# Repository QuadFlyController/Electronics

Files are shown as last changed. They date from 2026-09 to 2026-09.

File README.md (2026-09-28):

# QuadFlyController - Flight Controller Hardware

A high-performance, compact, 4-layer flight controller PCB engineered for quadcopters and small UAVs. Built around the STMicroelectronics STM32F411CEU6 MCU, featuring high-rate low-noise motion sensing, barometric altitude tracking, robust power management with dual-source automatic switching, and standard 30.5 mm × 30.5 mm mounting.

---

## 🚀 Key Specifications

| Subsystem | Component | Description |
| :--- | :--- | :--- |
| **Microcontroller (MCU)** | **STM32F411CEU6** | ARM Cortex-M4 @ 100 MHz, FPU, 512 KB Flash, 128 KB SRAM, external 25 MHz HSE oscillator |
| **Inertial Measurement (IMU)** | **ICM-42688-P** | High-precision 6-axis gyroscope & accelerometer on dedicated high-speed SPI bus with interrupt line |
| **Barometer / Altimeter** | **BMP390** | Ultra-low noise barometric pressure sensor on SPI bus for altitude hold |
| **Switching Regulator (Buck)** | **TPS62933** | High-efficiency 3A synchronous step-down converter providing stable +5V rail from battery |
| **Linear Regulator (LDO)** | **AP2112K-3.3** | Ultra-low dropout, low-noise 600 mA 3.3V LDO for clean MCU and analog sensor rails |
| **Power Path Switching** | **TPS2115A** | Seamless automatic power multiplexer between USB VBUS (+5V) and internal Buck converter (+5V) |
| **Transient Protection** | **SMBJ18A** | Bidirectional TVS diode protection on battery input |
| **USB Protection** | **USBLC6-2SC6** | Ultra-low capacitance ESD protection array on USB D+/D- lines |
| **USB Interface** | **USB Type-C (16-pin)** | Firmware flashing (DFU), telemetry, and configuration interface |
| **ESC Interface** | **JST-SH 8-Pin (1.0 mm)** | Standard 4-in-1 ESC connector (VBAT, GND, Motors 1–4, Current sensing) |

---

## 📐 PCB & Mechanical Specifications

- **Dimensions:** 45.0 mm × 45.0 mm with 3.5 mm corner radius
- **Mounting Hole Pattern:** Standard **30.5 mm × 30.5 mm**, 4.3 mm holes (M4, compatible with anti-vibration silicone grommets down to M3 hardware)
- **Layer Stack:** **4-Layer PCB**
  - **F.Cu (Top Layer):** High-speed signals, component breakout, top ground pour
  - **In1.Cu (Inner Layer 1):** Solid ground reference plane (GND)
  - **In2.Cu (Inner Layer 2):** Power distribution (+5V, +3.3V, +BATT) and cross-layer routing
  - **B.Cu (Bottom Layer):** Bottom ground plane and secondary signal routing
- **3D Mechanical Model:** Full 3D STEP model available in [`FlightController/CAD/FlightController.step`](FlightController/CAD/FlightController.step) for frame integration and enclosure design.

---

## 🔌 Pinout & Connector Definitions

### J3: 8-Pin JST-SH 4-in-1 ESC Connector (`SM08B-SRSS-TB`)

| Pin | Net Name | Function / Description |
| :---: | :--- | :--- |
| **1** | `+BATT` | Raw battery voltage input from ESC / PDB |
| **2** | `GND` | Power and signal ground return |
| **3** | `CUR` | Analog current sensing signal from ESC shunt sensor |
| **4** | `M1` | Motor 1 PWM / DShot signal output (STM32 Timer channel) |
| **5** | `M2` | Motor 2 PWM / DShot signal output (STM32 Timer channel) |
| **6** | `M3` | Motor 3 PWM / DShot signal output (STM32 Timer channel) |
| **7** | `M4` | Motor 4 PWM / DShot signal output (STM32 Timer channel) |
| **8** | `GND` | Ground return |

### External Pads & Test Points

- **UART (TX / RX):** External receiver connection (ELRS, Crossfire, SBUS) or GPS telemetry module.
- **SWD (SWDIO / SWCLK):** Hardware debug and in-circuit flashing with ST-Link or J-Link.
- **BOOT0:** Jumper/pad for STM32 internal ROM system bootloader (DFU mode over USB).
- **Status LEDs:**
  - `D1`: Power indicator
  - `D2`: User / Status LED (connected to STM32 GPIO)

---

## 📂 Repository Structure

```text
Electronics/
├── .gitignore                                 # Git ignore configuration
├── LICENSE                                    # License file
├── README.md                                  # Hardware documentation
├── FlightController_Schematic.pdf             # Exported full schematic PDF
│
└── FlightController/                          # KiCad 10 Project Directory
    ├── FlightController.kicad_pro             # KiCad project file
    ├── FlightController.kicad_pcb             # KiCad 4-layer PCB layout
    ├── FlightController.kicad_sch             # Root schematic sheet
    ├── MCU.kicad_sch                          # STM32F411CEU6 microcontroller sheet
    ├── IMU.kicad_sch                          # ICM-42688-P & BMP390 sensor sheet
    ├── PowerManagement.kicad_sch              # Power rails, buck, LDO, & USB sheet
    ├── fp-lib-table                           # Footprint library table
    ├── sym-lib-table                          # Symbol library table
    ├── fabrication-toolkit-options.json       # Production generation settings
    │
    ├── CAD/                                   # 3D Mechanical Models
    │   └── FlightController.step              # Complete 3D STEP assembly of the PCB
    │
    └── production/                            # Manufacturing & Assembly Files
        ├── FlightController.zip               # Gerbers & Drill archive (RS-274X / Excellon)
        ├── bom.csv                            # Bill of Materials (with LCSC part numbers)
        ├── positions.csv                      # Pick-and-Place (CPL) centroid coordinates
        ├── designators.csv                    # Component designator mapping
        └── netlist.ipc                        # IPC-D-356 netlist for bare-board testing
```

---

## 🏭 Manufacturing & Assembly (PCBA)

The files in [`FlightController/production/`](FlightController/production/) are pre-configured and formatted for rapid quoting and ordering with PCB manufacturers (such as JLCPCB, PCBWay, etc.):

1. **PCB Fabrication (Gerber & Drill):**
   - Upload [`FlightController/production/FlightController.zip`](FlightController/production/FlightController.zip).
   - Layers: **4 Layers**
   - Dimensions: **45 mm × 45 mm**
2. **SMT Assembly (PCBA):**
   - **BOM File:** Upload [`FlightController/production/bom.csv`](FlightController/production/bom.csv) (includes pre-matched LCSC part numbers for automated component sourcing).
   - **CPL / Centroid File:** Upload [`FlightController/production/positions.csv`](FlightController/production/positions.csv).
3. **Bare-Board Electrical Test:**
   - [`FlightController/production/netlist.ipc`](FlightController/production/netlist.ipc) is provided for automated flying-probe netlist verification.

---

## 🛠️ Design & Development Environment

- **EDA Software:** [KiCad EDA v10.x](https://www.kicad.org/)
- **To Open the Project:** Launch KiCad and open [`FlightController/FlightController.kicad_pro`](FlightController/FlightController.kicad_pro).
- **Viewing the Schematic without KiCad:** Open [`FlightController_Schematic.pdf`](FlightController_Schematic.pdf).

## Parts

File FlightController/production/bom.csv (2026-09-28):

Designator | Footprint | Quantity | Value | LCSC Part #
C1, C2, C28 | 0805 | 3 | 10μF X7R | C326595
C10, C11 | 0402 | 2 | 14pF C0G | C5360816
C12, C13, C14, C17, C18, C21, C27, C29, C30, C4, C7, C8, C9 | 0603 | 13 | 0.1μF X7R | C1590
C15 | 0603 | 1 | 2.2μF X7R | C43922
C16 | 0603 | 1 | 10nF X7R | C1589
C19, C20 | 1206 | 2 | 10μF X7R 50V | C89632
C22 | 0603 | 1 | 33nF X7R | C1614
C23 | 0603 | 1 | 0.1μF X7R 16V | C1590
C24, C25 | 1206 | 2 | 22μF X5R 35V | C342620
C26 | 0603 | 1 | 0.1μF X7R 35V | C385964
C3 | 0603 | 1 | 1μF X7R | C5199872
C5, C6 | 0603 | 2 | 4.7μF X7R | C6119822
CR1 | SMBJ18A | 1 | SMBJ18A | C10212
D1, D2 | 0603 | 2 | LED | C2286
J3 | XY-SM08B-SRSS-TB | 1 | SM08B-SRSS-TBLFSN | C54582896
L1 | 74439346068 | 1 | 74439346068 | C2041388
R1 | R_0603 | 1 | 100kΩ | C25803
R10 | 0603 | 1 | 53.6k | C23074
R11 | R_0603 | 1 | 10Ω | C22859
R12 | 0603 | 1 | 400 | C5841024
R13, R16, R5, R6, R7, R8 | R_0603 | 6 | 10kΩ | C25804
R14 | 1206 | 1 | 510k | C2774961
R15 | 1206 | 1 | 200k | C5720887
R17, R19 | R_0603 | 2 | 1kΩ | C21190
R18 | R_0603 | 1 | 1.5kΩ | C22843
R2, R3, R4 | R_0603 | 3 | 5.1kΩ | C23186
R9 | 0603 | 1 | 10.2k | C22772
U1 | SOT-23-5_HandSoldering | 1 | AP2112K-3.3 | C23380830
U2 | SOT-23-6_Handsoldering | 1 | USBLC6-2SC6 | C7519
U6 | SOT-583-8 | 1 | TPS62933 | C3200405
U7 | TPS2115ADRBR | 1 | TPS2115ADRBR | C140321
USB1 | USB-C_SMD-TYPE-C-31-M-12 | 1 | USB-TYPE-C-018 | C2927038
Y1 | CRYSTAL-SMD_4P-L3.2-W2.5-BL | 1 | 25MHz_GND24 | C9006

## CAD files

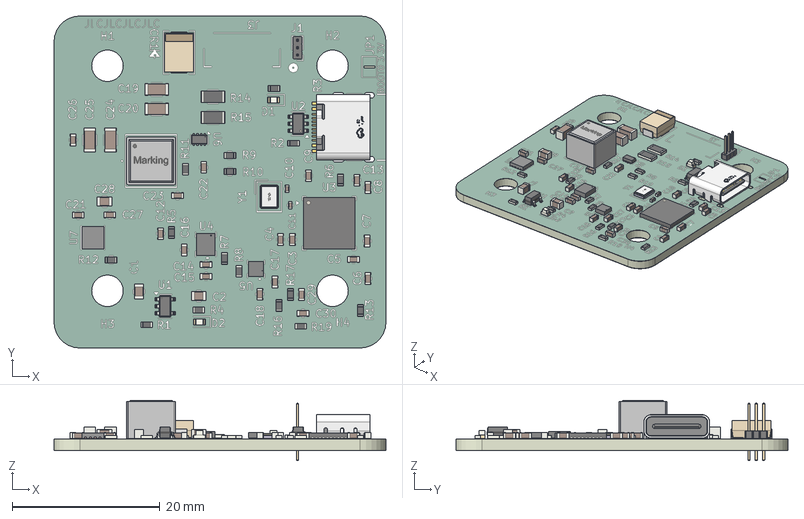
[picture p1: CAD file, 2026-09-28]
FlightController/CAD/FlightController.step
45.0 x 45.0 x 8.20 mm
C_0603_1608Metric x 21
R_0603_1608Metric x 17
C_0402_1005Metric x 2
C_0805_2012Metric x 3
PinHeader_1x03_P100mm_Vertical
C_1206_3216Metric x 4
QFN-48-1EP_7x7mm_Pitch0.5mm
LED_0603_1608Metric x 2
SOT-583-8
SOT-23-6
R_1206_3216Metric x 2
SOT-23-5
OSC-SMD_L3.2-W1.5-H0.8
BODY-SON
USB-C_SMD-TYPE-C-31-M-12
Fli650C_silkscreen x 2
Fli650C_soldermask x 2
Fli650C_PCB

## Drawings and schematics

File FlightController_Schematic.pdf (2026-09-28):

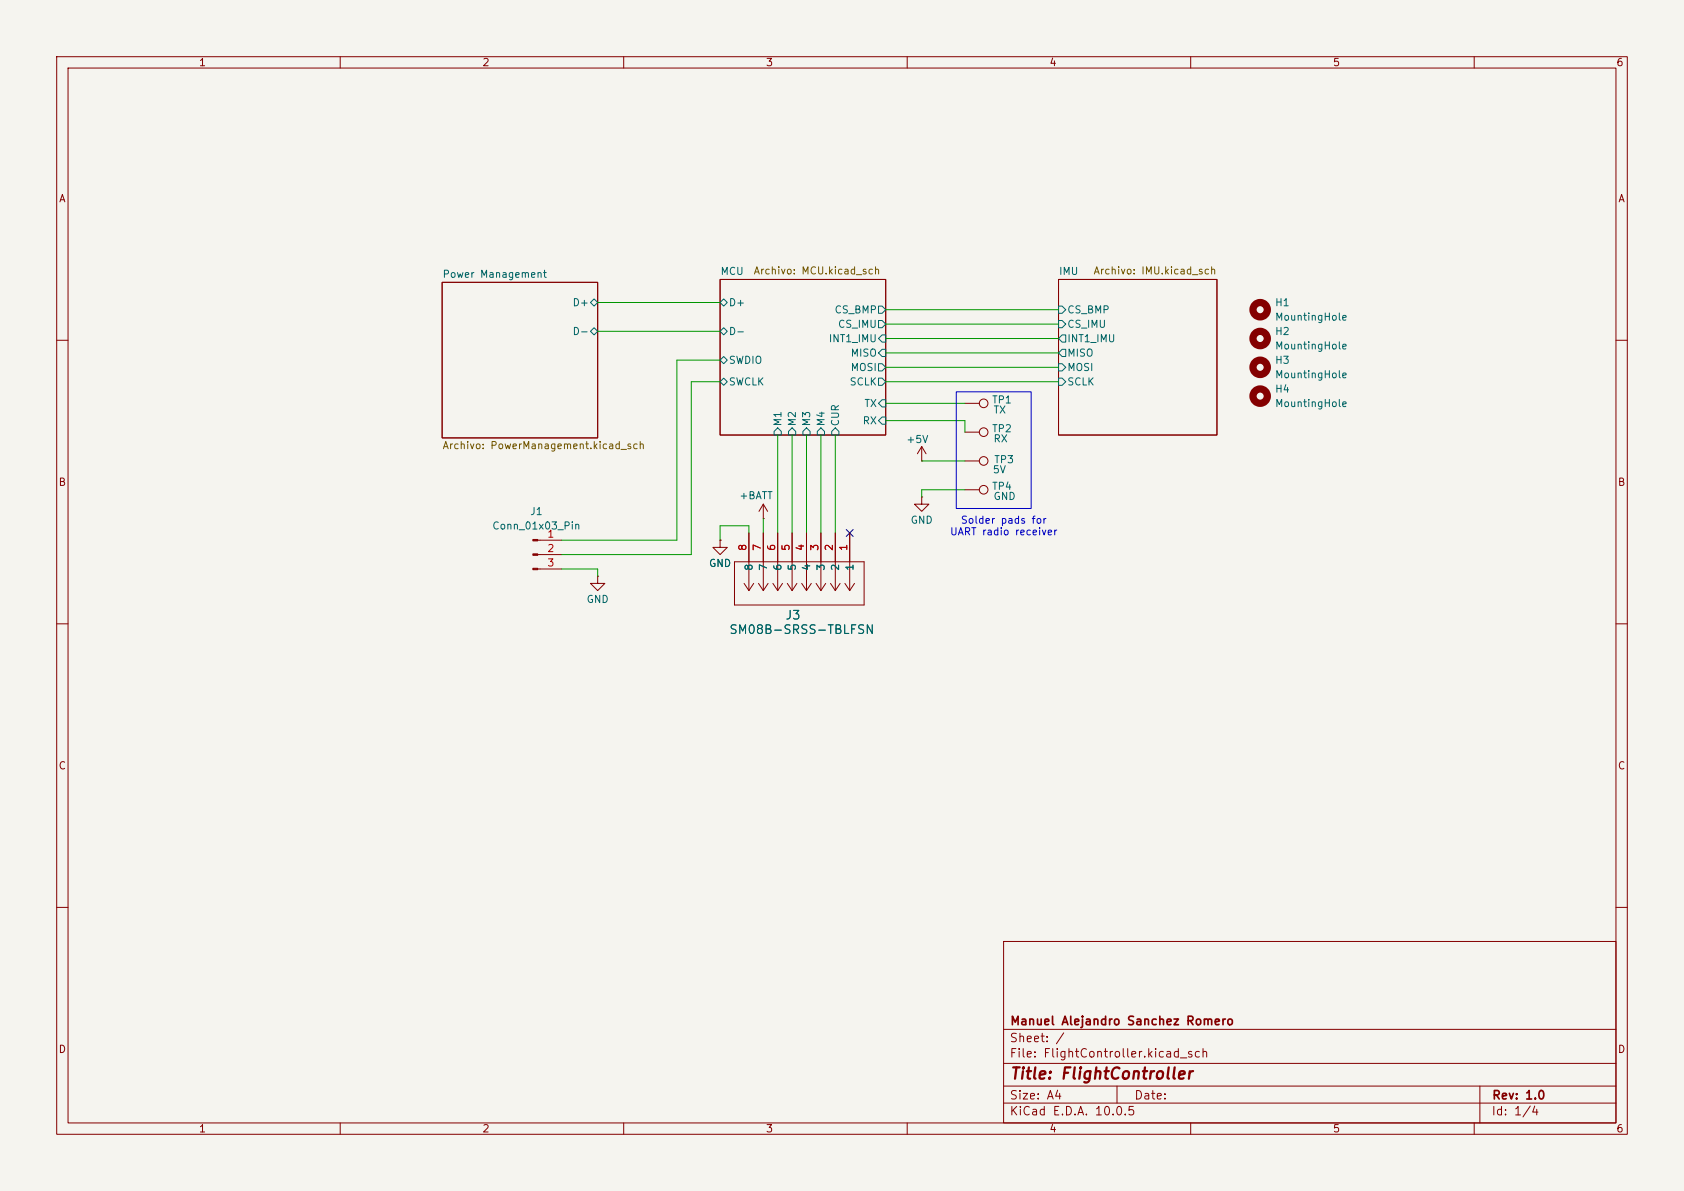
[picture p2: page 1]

SWDIO MCU Archivo: MCU.kicad_sch

Manuel Alejandro Sanchez Romero
Sheet: /
File: FlightController.kicad_sch
Title: FlightController

Size: A4 | Rev: 1.0
KiCad E.D.A. 10.0.5 | Id: 1/4

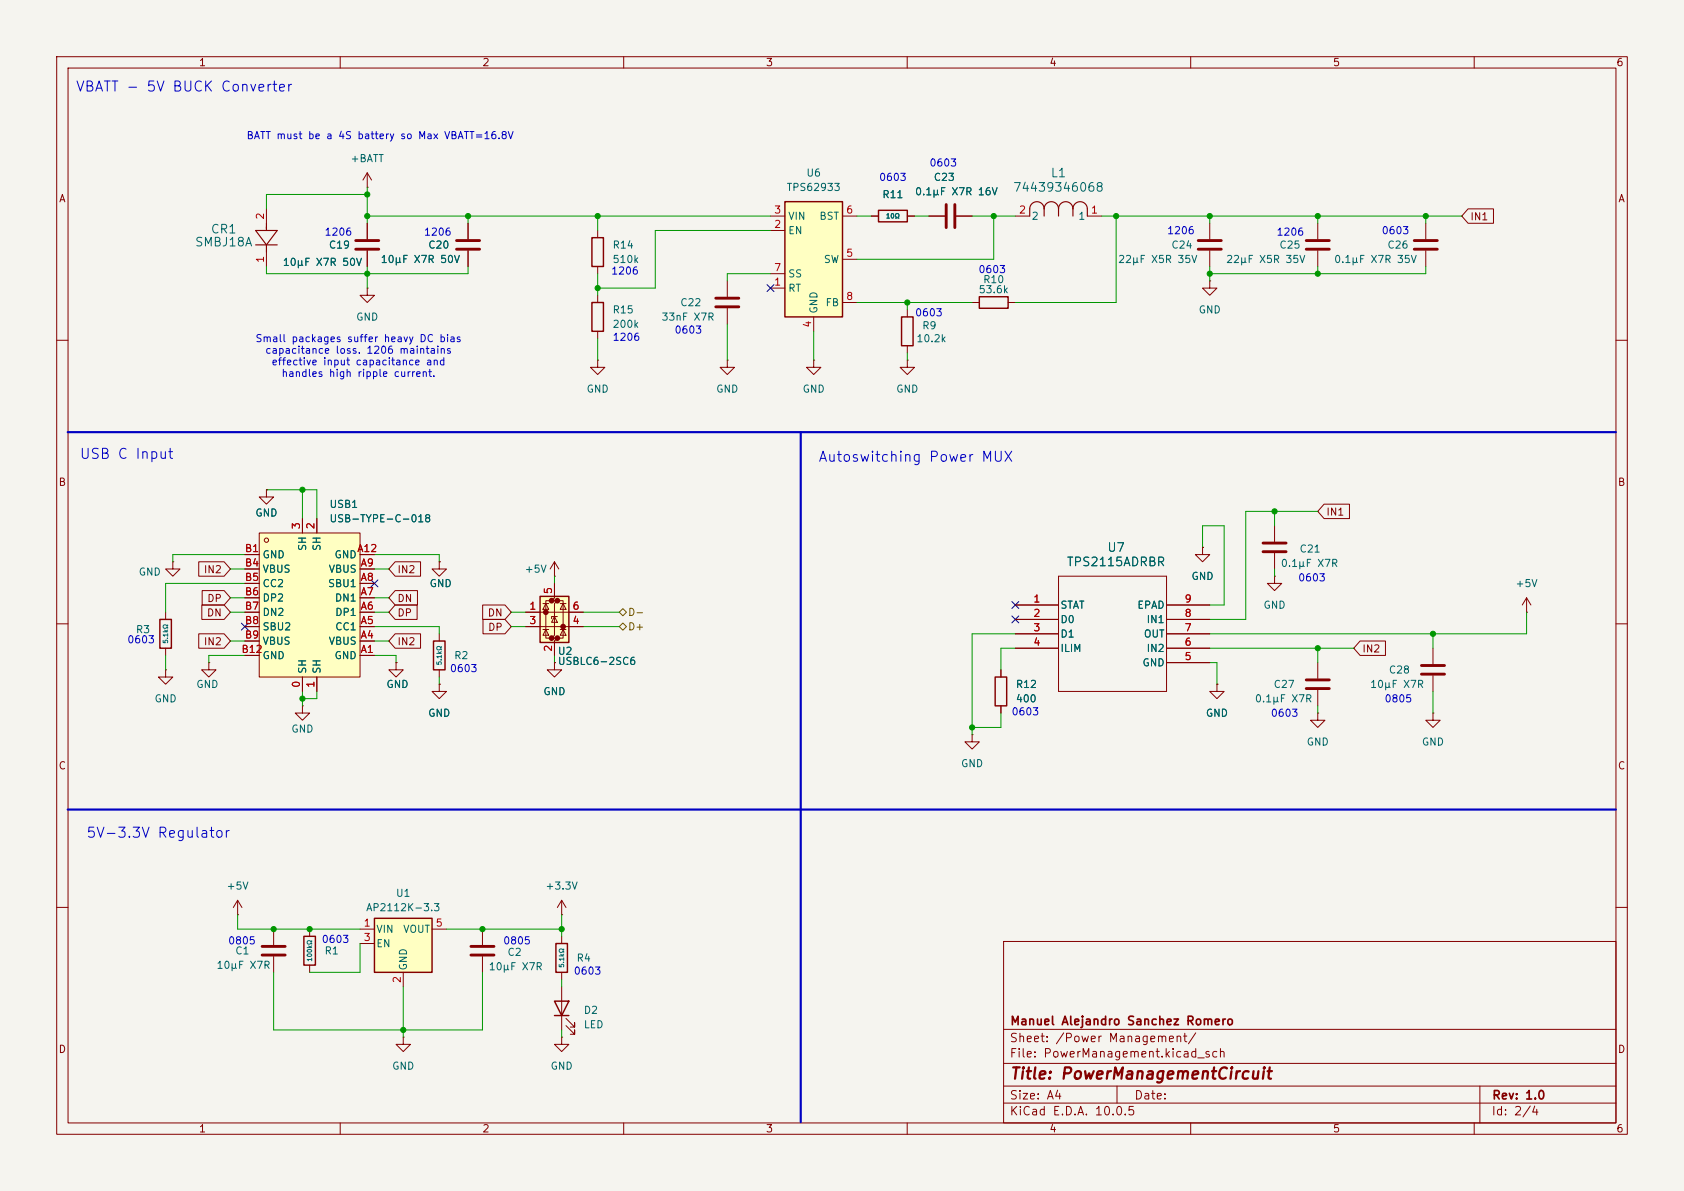
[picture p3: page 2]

200k GND
Small packages suffer heavy DC bias capacitance loss. 1206 maintains effective input capacitance and

3 GND A1 VBUS A4 CC1 A5 DP1 A6 DN1 A7 SBU1 A8 VBUS A9 GNDA12 GND B1

Manuel Alejandro Sanchez Romero
Sheet: /Power Management/
File: PowerManagement.kicad_sch
Title: PowerManagementCircuit

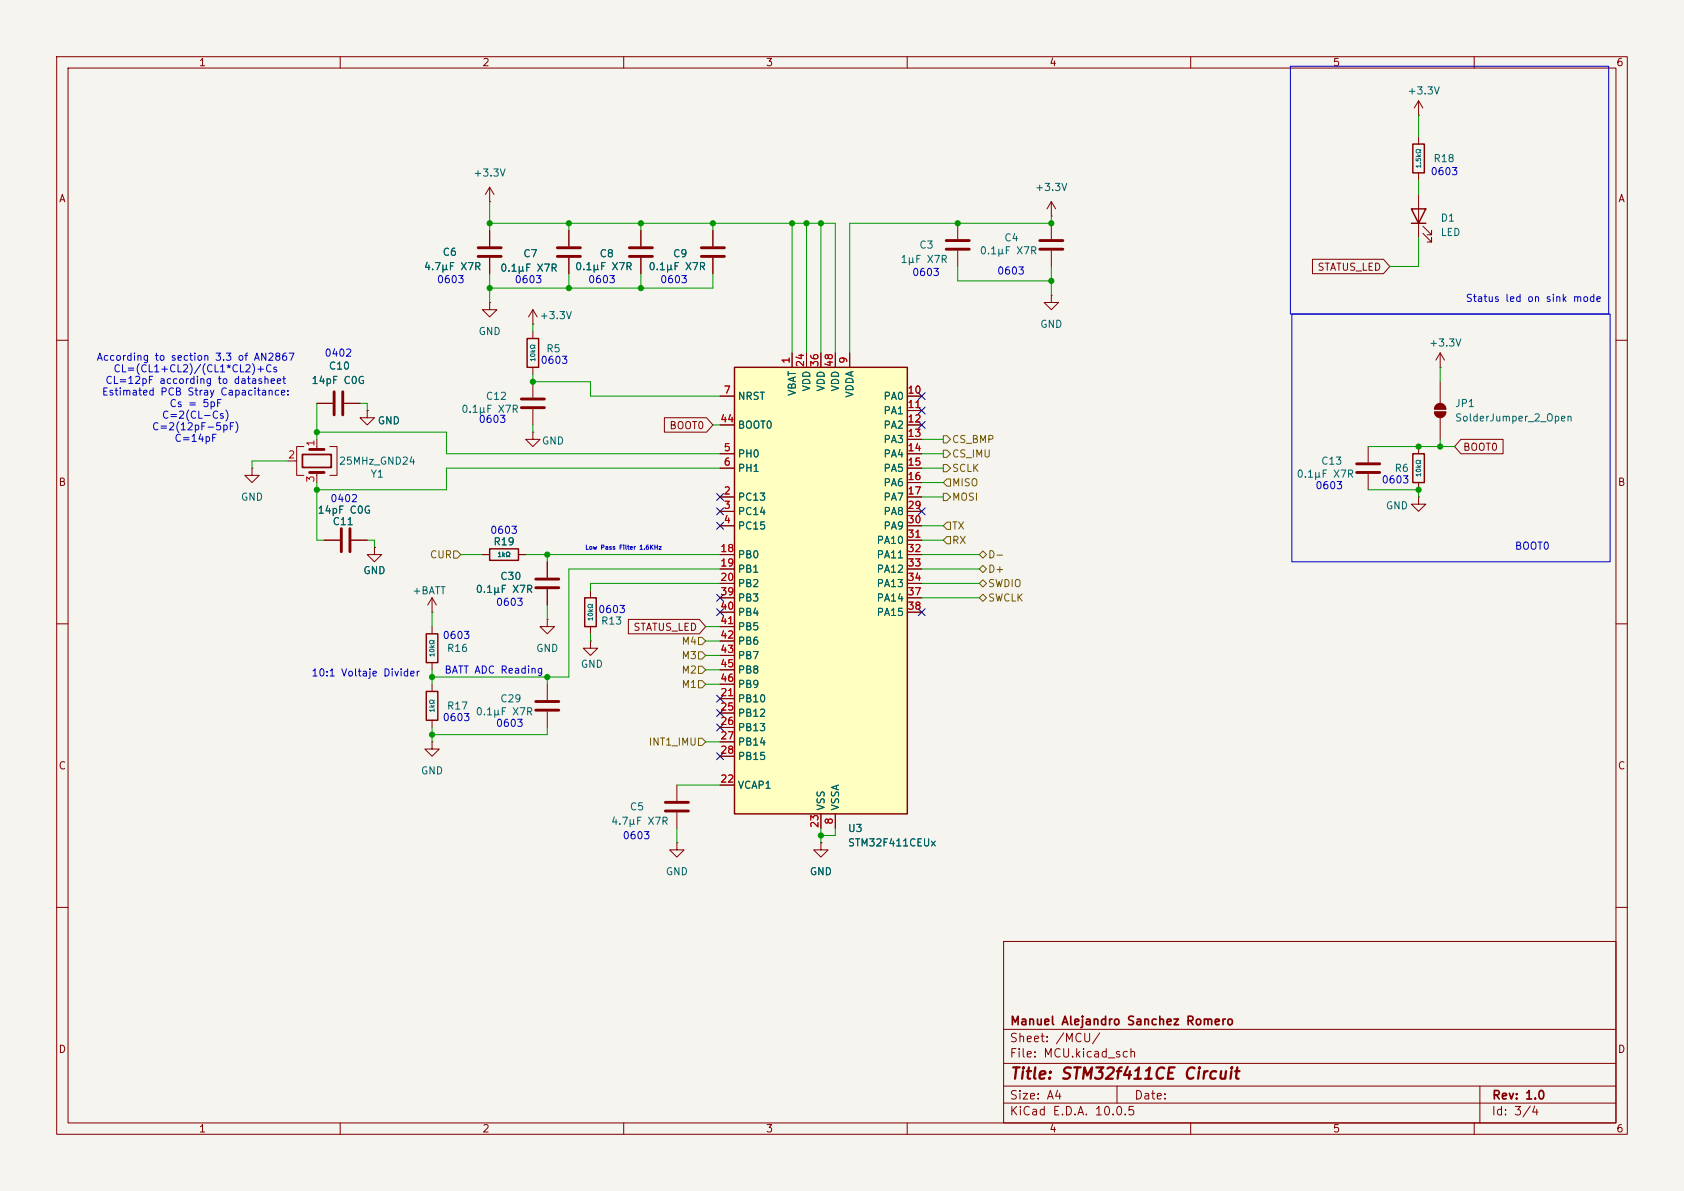
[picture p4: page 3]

According to section 3.3 of AN2867 CL=(CL1+CL2)/(CL1*CL2)+Cs

CL=12pF according to datasheet Estimated PCB Stray Capacitance: Cs = 5pF

Manuel Alejandro Sanchez Romero
Sheet: /MCU/
File: MCU.kicad_sch
Title: STM32f411CE Circuit

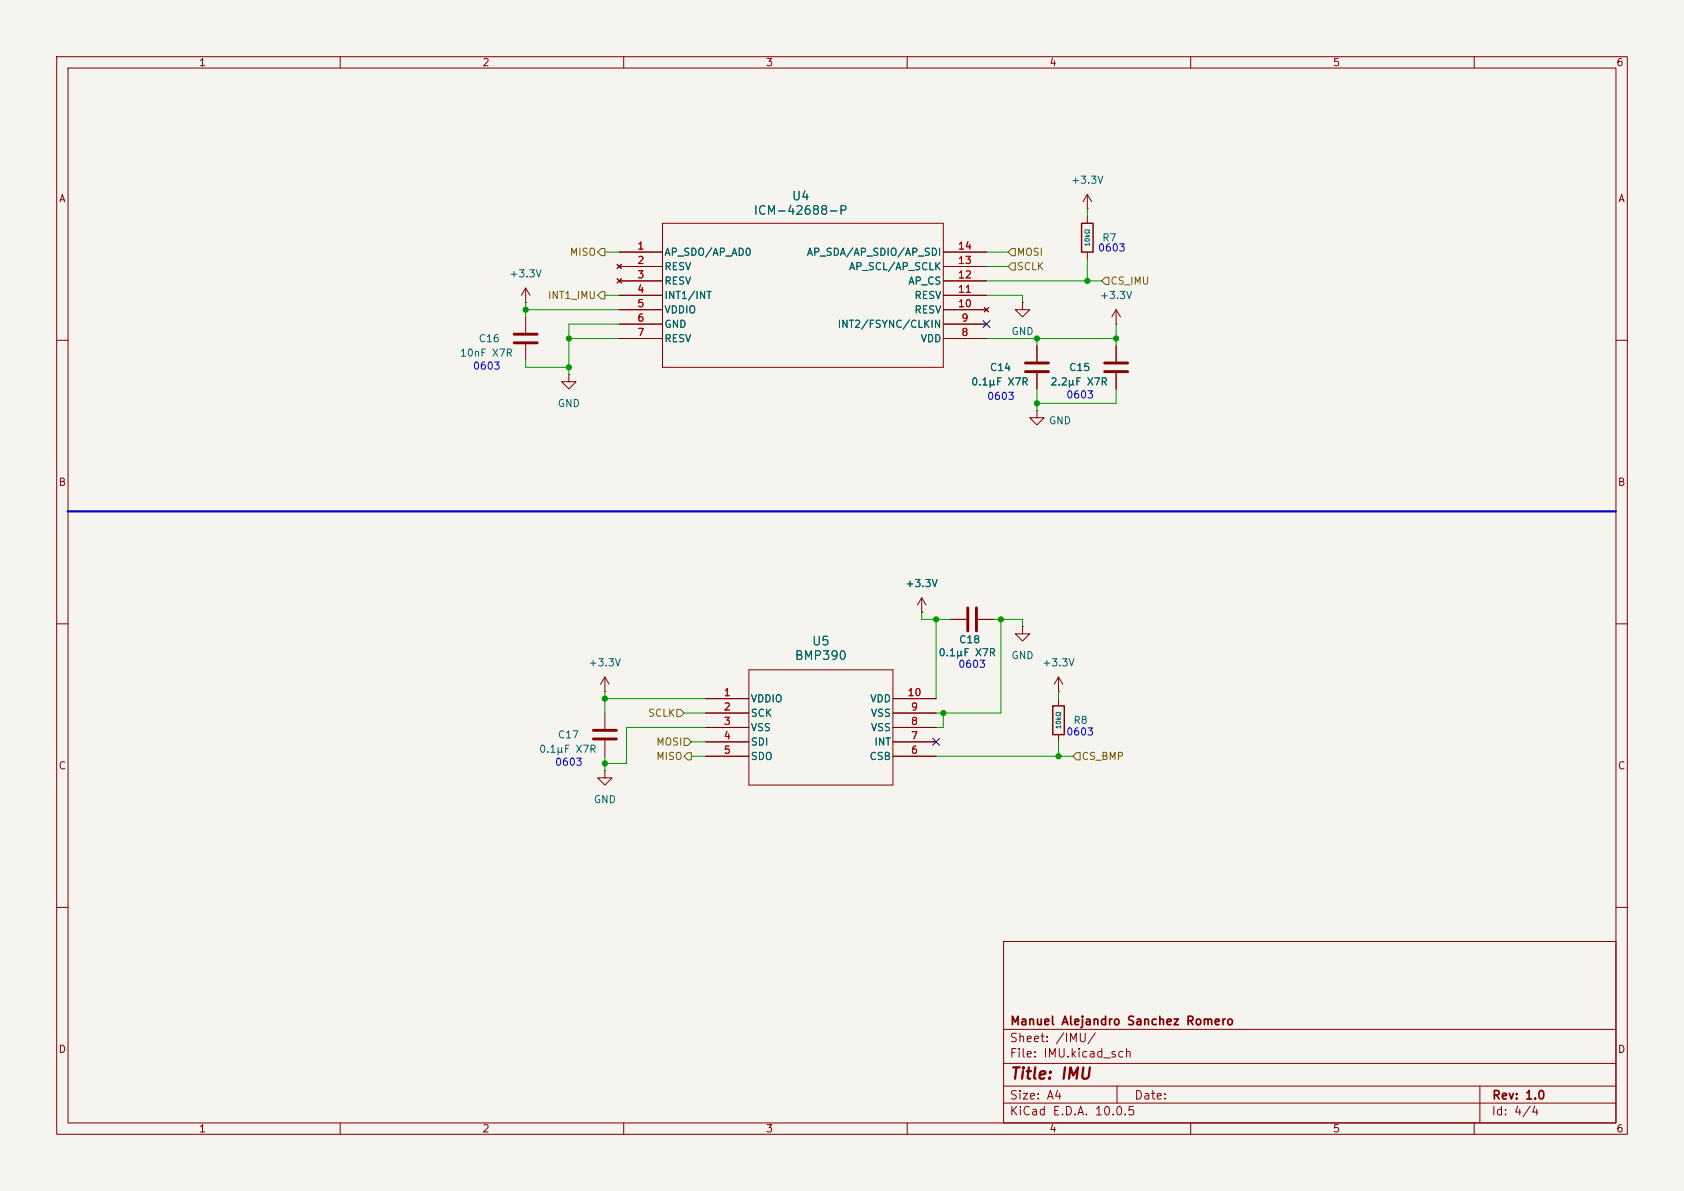
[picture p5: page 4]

Manuel Alejandro Sanchez Romero
Sheet: /IMU/
File: IMU.kicad_sch
Title: IMU

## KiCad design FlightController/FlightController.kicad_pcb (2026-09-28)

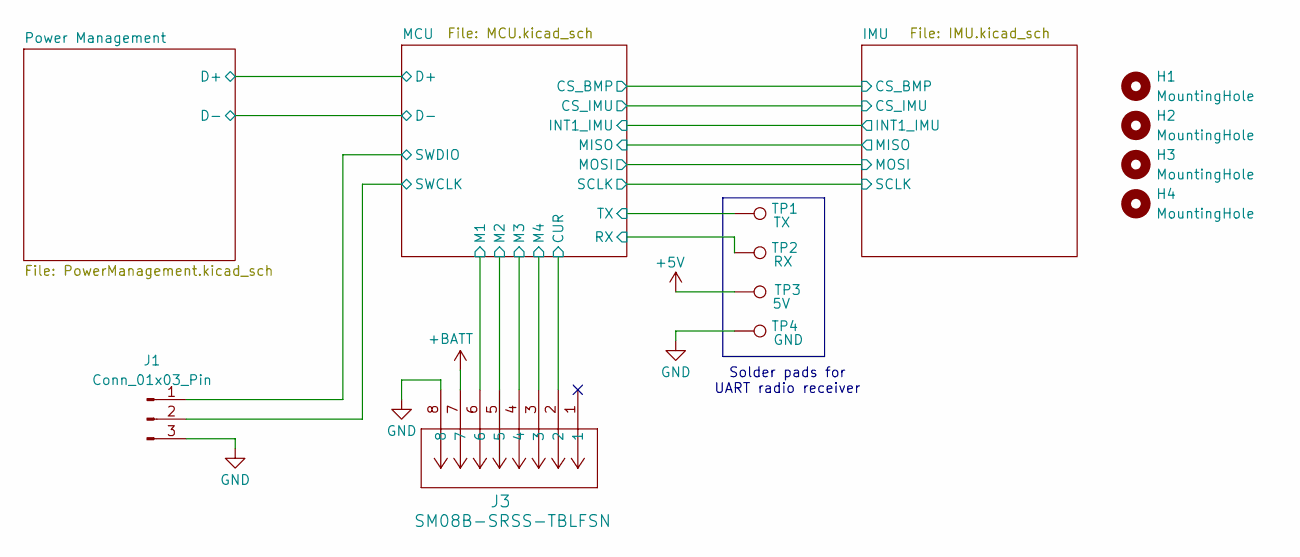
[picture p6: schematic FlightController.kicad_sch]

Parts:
H1, H2, H3, H4: MountingHole; MountingHole_4.3mm_M4
J1: Conn_01x03_Pin; PinHeader_1x03_P1.00mm_Vertical
J3: SM08B-SRSS-TBLFSN; XY-SM08B-SRSS-TB; LCSC C54582896
TP1: TX; TestPoint_Pad_3.0x3.0mm
TP2: RX; TestPoint_Pad_3.0x3.0mm
TP3: 5V; TestPoint_Pad_3.0x3.0mm
TP4: GND; TestPoint_Pad_3.0x3.0mm

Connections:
+5V: TP3.1 (1_1); also elsewhere on the board
+BATT: J3.7; also elsewhere on the board
/MCU/CUR: J3.2; also elsewhere on the board
/MCU/M1: J3.6; also elsewhere on the board
/MCU/M2: J3.5; also elsewhere on the board
/MCU/M3: J3.4; also elsewhere on the board
/MCU/M4: J3.3; also elsewhere on the board
/MCU/RX: TP2.1 (1_1); also elsewhere on the board
/MCU/SWCLK: J1.2; also elsewhere on the board
/MCU/SWDIO: J1.1; also elsewhere on the board
/MCU/TX: TP1.1 (1_1); also elsewhere on the board
GND: J1.3, J3.8, TP4.1 (1_1); also elsewhere on the board

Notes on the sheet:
Solder pads for UART radio receiver

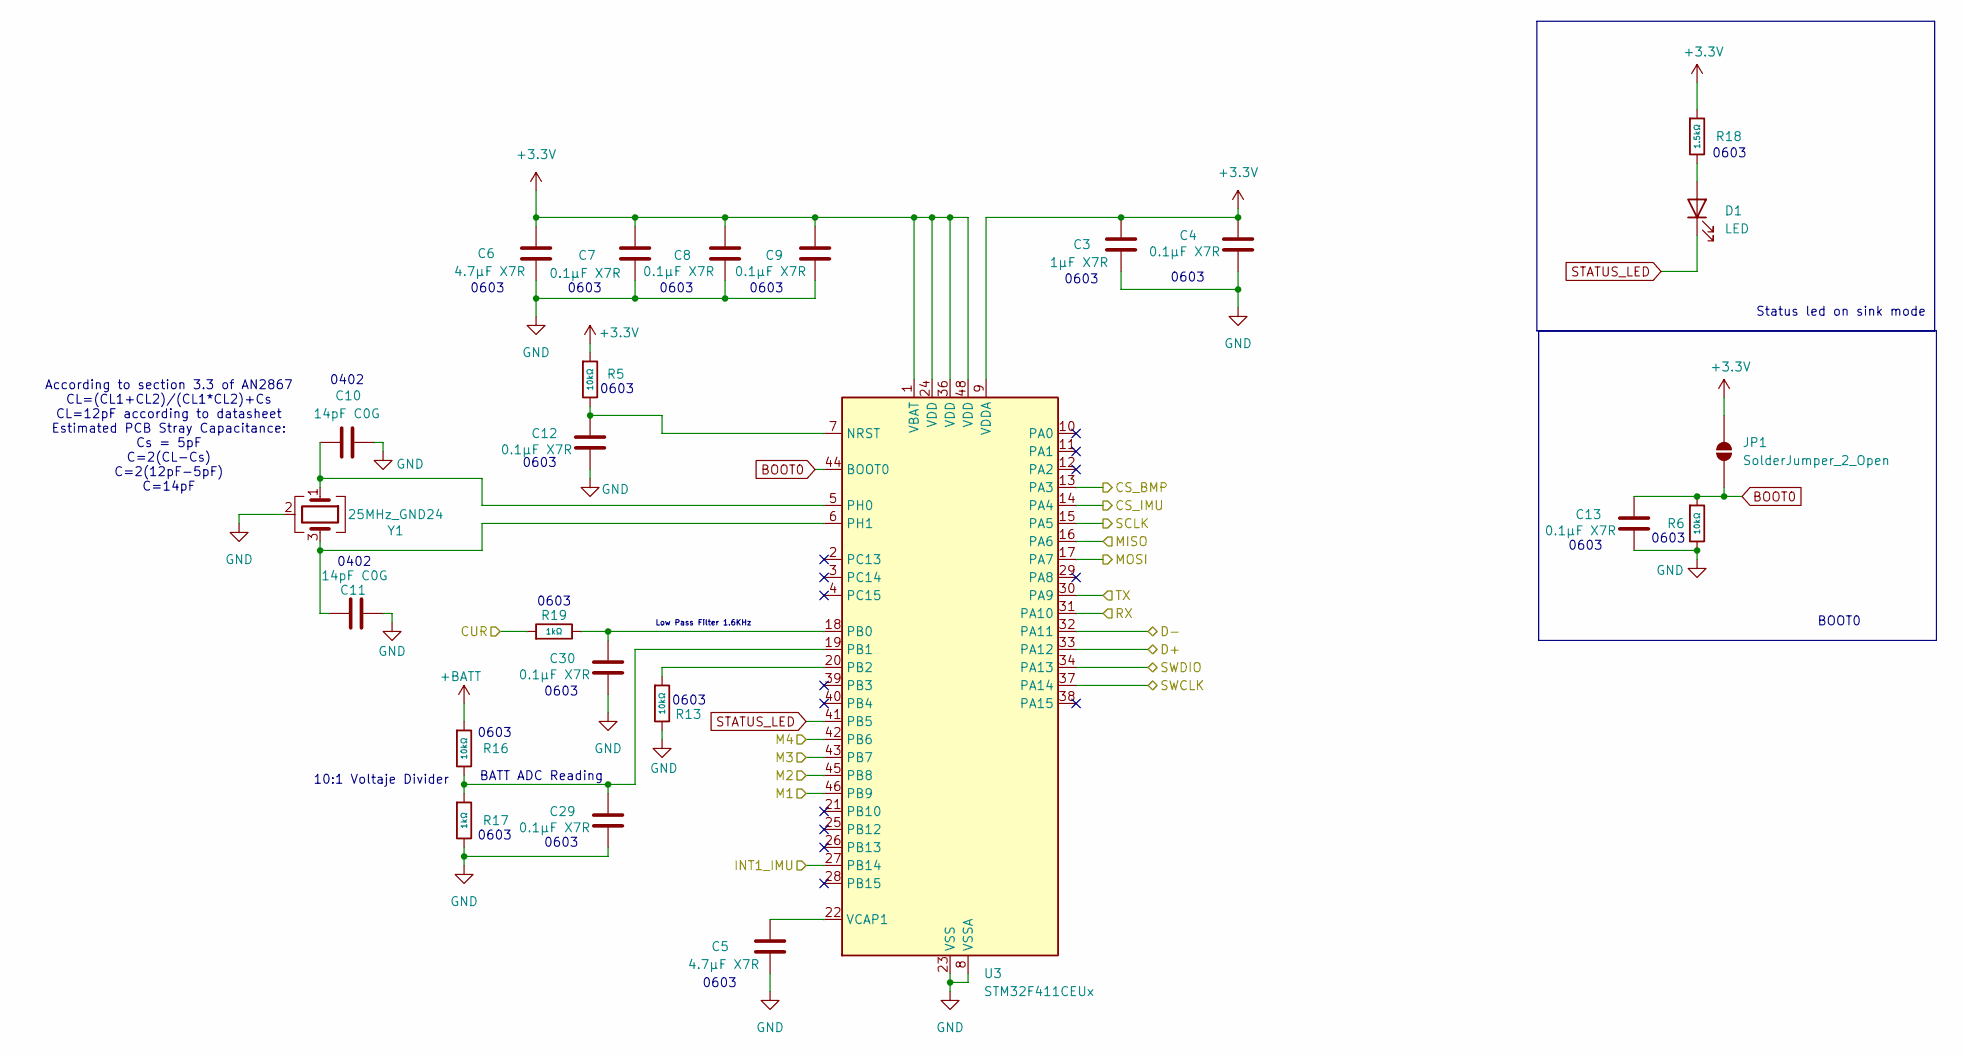
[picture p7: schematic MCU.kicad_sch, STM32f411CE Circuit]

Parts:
C3: 1μF X7R; C_0603_1608Metric_Pad1.08x0.95mm_HandSolder; LCSC C5199872
C4, C7, C8, C9, C12, C13, C29, C30: 0.1μF X7R; C_0603_1608Metric_Pad1.08x0.95mm_HandSolder; LCSC C1590
C5, C6: 4.7μF X7R; C_0603_1608Metric_Pad1.08x0.95mm_HandSolder; LCSC C6119822
C10, C11: 14pF C0G; C_0402_1005Metric_Pad0.74x0.62mm_HandSolder; LCSC C5360816
D1: LED; LED_0603_1608Metric; LCSC C2286
JP1: SolderJumper_2_Open; SolderJumper-2_P1.3mm_Open_Pad1.0x1.5mm
R5, R6, R13, R16: 10kΩ; R_0603; Overload Voltage (Max) 75V; Tolerance ±1%; Part 0603WAF1002T5E; LCSC C25804
R17, R19: 1kΩ; R_0603; Overload Voltage (Max) 75V; Tolerance ±1%; Part 0603WAF1001T5E; LCSC C21190
R18: 1.5kΩ; R_0603; Overload Voltage (Max) 75V; Tolerance ±1%; Part 0603WAF1501T5E; LCSC C22843
U3: STM32F411CEUx; QFN-48-1EP_7x7mm_P0.5mm_EP5.6x5.6mm
Y1: 25MHz_GND24; CRYSTAL-SMD_4P-L3.2-W2.5-BL; LCSC C9006

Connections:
+3.3V: C3.1, C4.1, C6.1, C7.1, C8.1, C9.1, JP1.2 (B), R5.1, R18.1, U3.1 (VBAT), U3.9 (VDDA), U3.24 (VDD), U3.36 (VDD), U3.48 (VDD); also elsewhere on the board
+BATT: R16.1; also elsewhere on the board
/IMU/CS_BMP: U3.13 (PA3); also elsewhere on the board
/IMU/CS_IMU: U3.14 (PA4); also elsewhere on the board
/IMU/INT1_IMU: U3.27 (PB14); also elsewhere on the board
/IMU/MISO: U3.16 (PA6); also elsewhere on the board
/IMU/MOSI: U3.17 (PA7); also elsewhere on the board
/IMU/SCLK: U3.15 (PA5); also elsewhere on the board
/MCU/CUR: R19.1; also elsewhere on the board
/MCU/D+: U3.33 (PA12); also elsewhere on the board
/MCU/D-: U3.32 (PA11); also elsewhere on the board
/MCU/M1: U3.46 (PB9); also elsewhere on the board
/MCU/M2: U3.45 (PB8); also elsewhere on the board
/MCU/M3: U3.43 (PB7); also elsewhere on the board
/MCU/M4: U3.42 (PB6); also elsewhere on the board
/MCU/RX: U3.31 (PA10); also elsewhere on the board
/MCU/SWCLK: U3.37 (PA14); also elsewhere on the board
/MCU/SWDIO: U3.34 (PA13); also elsewhere on the board
/MCU/TX: U3.30 (PA9); also elsewhere on the board
BOOT0: C13.1, JP1.1 (A), R6.1, U3.44 (BOOT0)
GND: C3.2, C4.2, C5.2, C6.2, C7.2, C8.2, C9.2, C10.1, C11.2, C12.2, C13.2, C29.2, C30.2, R6.2, R13.2, R17.2, U3.8 (VSSA), U3.23 (VSS), U3.35 (VSS), U3.47 (VSS), U3.49 (VSS), Y1.2 (G), Y1.4 (G); also elsewhere on the board
unnamed: D1.2 (A), R18.2
unnamed: C12.1, R5.2, U3.7 (NRST)
unnamed: C30.1, R19.2, U3.18 (PB0)
unnamed: C29.1, R16.2, R17.1, U3.19 (PB1)
unnamed: R13.1, U3.20 (PB2)
unnamed: C10.2, U3.5 (PH0), Y1.1
unnamed: C11.1, U3.6 (PH1), Y1.3
unnamed: C5.1, U3.22 (VCAP1)
STATUS_LED: D1.1 (K), U3.41 (PB5)

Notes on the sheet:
0603
BOOT0
BATT ADC Reading
Status led on sink mode
0402
Low Pass Filter 1.6KHz
10:1 Voltaje Divider
According to section 3.3 of AN2867 CL=(CL1+CL2)/(CL1*CL2)+Cs CL=12pF according to datasheet Estimated PCB Stray Capacitance: Cs = 5pF C=2(CL-Cs) C=2(12pF-5pF) C=14pF

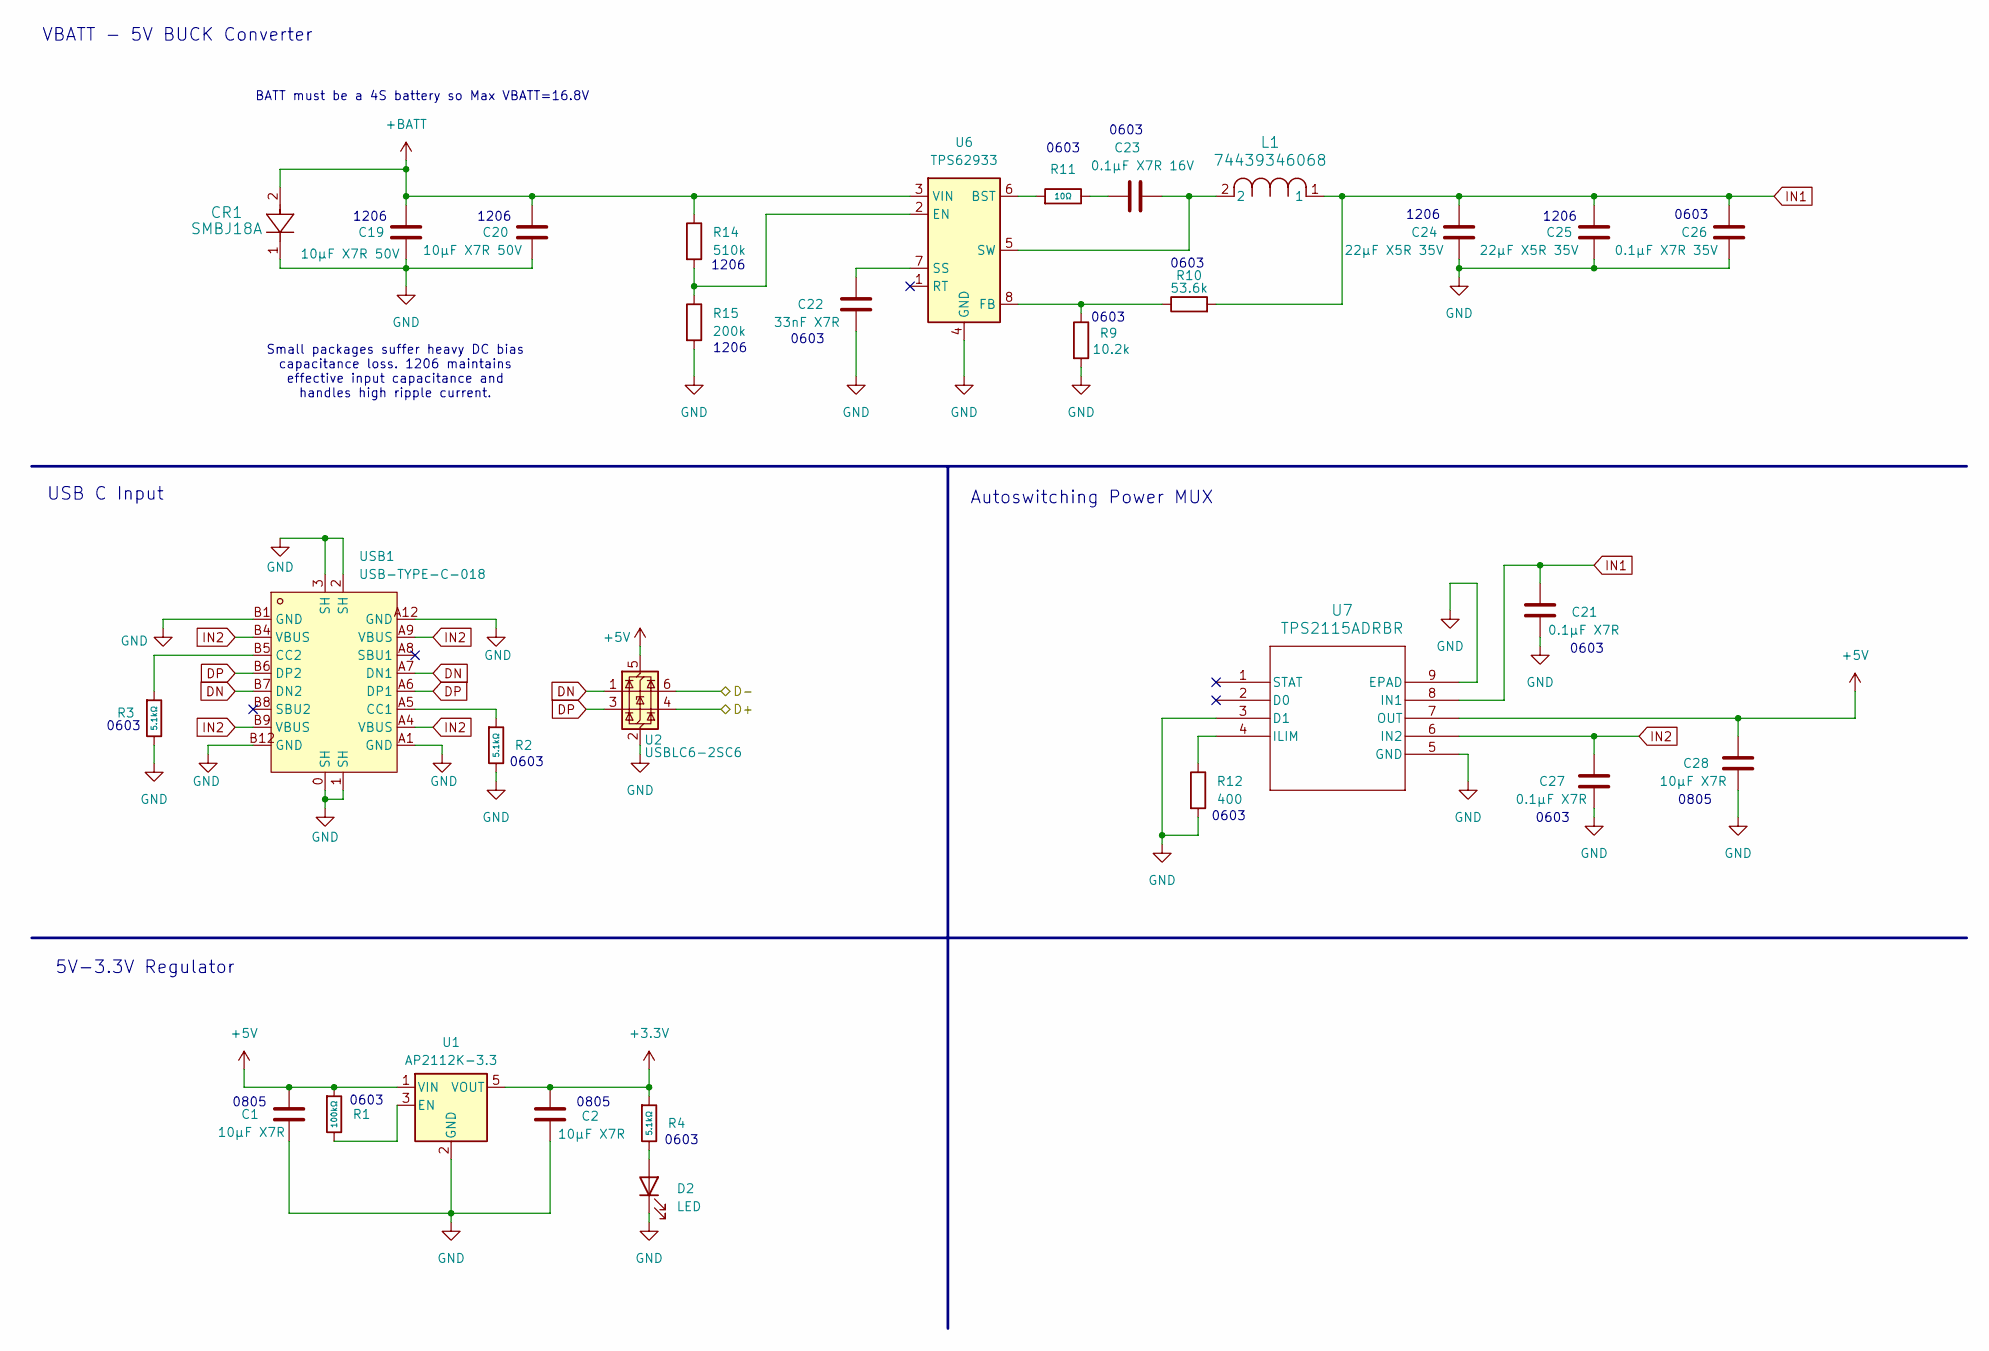
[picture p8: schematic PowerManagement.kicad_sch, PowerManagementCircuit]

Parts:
C1, C2, C28: 10μF X7R; C_0805_2012Metric_Pad1.18x1.45mm_HandSolder; LCSC C326595
C19, C20: 10μF X7R 50V; C_1206_3216Metric_Pad1.33x1.80mm_HandSolder; LCSC C89632
C21, C27: 0.1μF X7R; C_0603_1608Metric_Pad1.08x0.95mm_HandSolder; LCSC C1590
C22: 33nF X7R; C_0603_1608Metric_Pad1.08x0.95mm_HandSolder; LCSC C1614
C23: 0.1μF X7R 16V; C_0603_1608Metric_Pad1.08x0.95mm_HandSolder; LCSC C1590
C24, C25: 22μF X5R 35V; C_1206_3216Metric_Pad1.33x1.80mm_HandSolder; LCSC C342620
C26: 0.1μF X7R 35V; C_0603_1608Metric_Pad1.08x0.95mm_HandSolder; LCSC C385964
CR1: SMBJ18A; LCSC C10212
D2: LED; LED_0603_1608Metric; LCSC C2286
L1: 74439346068; LCSC C2041388
R1: 100kΩ; R_0603; Overload Voltage (Max) 75V; Tolerance ±1%; Part 0603WAF1003T5E; LCSC C25803
R2, R3, R4: 5.1kΩ; R_0603; Overload Voltage (Max) 75V; Tolerance ±1%; Part 0603WAF5101T5E; LCSC C23186
R9: 10.2k; R_0603_1608Metric_Pad0.98x0.95mm_HandSolder; LCSC C22772
R10: 53.6k; R_0603_1608Metric_Pad0.98x0.95mm_HandSolder; LCSC C23074
R11: 10Ω; R_0603; Overload Voltage (Max) 75V; Tolerance ±1%; Part 0603WAF100JT5E; LCSC C22859
R12: 400; R_0603_1608Metric_Pad0.98x0.95mm_HandSolder; LCSC C5841024
R14: 510k; R_1206_3216Metric_Pad1.30x1.75mm_HandSolder; LCSC C2774961
R15: 200k; R_1206_3216Metric_Pad1.30x1.75mm_HandSolder; LCSC C5720887
U1: AP2112K-3.3; SOT-23-5_HandSoldering; LCSC C23380830
U2: USBLC6-2SC6; SOT-23-6_Handsoldering; LCSC C7519
U6: TPS62933; SOT-583-8; LCSC C3200405
U7: TPS2115ADRBR; LCSC C140321
USB1: USB-TYPE-C-018; USB-C_SMD-TYPE-C-31-M-12; MPN USB-TYPE-C-018; LCSC Part C2927038

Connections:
+3.3V: C2.1, R4.1, U1.5 (VOUT); also elsewhere on the board
+5V: C1.1, C28.1, R1.1, U1.1 (VIN), U2.5 (VBUS), U7.7 (OUT); also elsewhere on the board
+BATT: C19.1, C20.1, CR1.2, R14.1, U6.3 (VIN); also elsewhere on the board
/MCU/D+: U2.4 (I/O2); also elsewhere on the board
/MCU/D-: U2.6 (I/O1); also elsewhere on the board
DN: U2.1 (I/O1), USB1.A7 (DN1), USB1.B7 (DN2)
DP: U2.3 (I/O2), USB1.A6 (DP1), USB1.B6 (DP2)
GND: C1.2, C2.2, C19.2, C20.2, C21.2, C22.2, C24.2, C25.2, C26.2, C27.2, C28.2, CR1.1, D2.1 (K), R2.2, R3.2, R9.2, R12.2, R15.2, U1.2 (GND), U2.2 (GND), U6.4 (GND), U7.3 (D1), U7.5 (GND), U7.9 (EPAD), USB1.0 (SH), USB1.1 (SH), USB1.2 (SH), USB1.3 (SH), USB1.A1 (GND), USB1.A12 (GND), USB1.B1 (GND), USB1.B12 (GND); also elsewhere on the board
IN1: C21.1, C24.1, C25.1, C26.1, L1.1, R10.2, U7.8 (IN1)
IN2: C27.1, U7.6 (IN2), USB1.A4 (VBUS), USB1.A9 (VBUS), USB1.B4 (VBUS), USB1.B9 (VBUS)
unnamed: C23.2, R11.2
unnamed: D2.2 (A), R4.2
unnamed: R1.2, U1.3 (EN)
unnamed: R11.1, U6.6 (BST)
unnamed: R14.2, R15.1, U6.2 (EN)
unnamed: R9.1, R10.1, U6.8 (FB)
unnamed: C22.1, U6.7 (SS)
unnamed: C23.1, L1.2, U6.5 (SW)
unnamed: R12.1, U7.4 (ILIM)
unnamed: R2.1, USB1.A5 (CC1)
unnamed: R3.1, USB1.B5 (CC2)

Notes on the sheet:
0603
Small packages suffer heavy DC bias capacitance loss. 1206 maintains effective input capacitance and handles high ripple current.
0805
Autoswitching Power MUX
1206
VBATT - 5V BUCK Converter
USB C Input
BATT must be a 4S battery so Max VBATT=16.8V
5V-3.3V Regulator

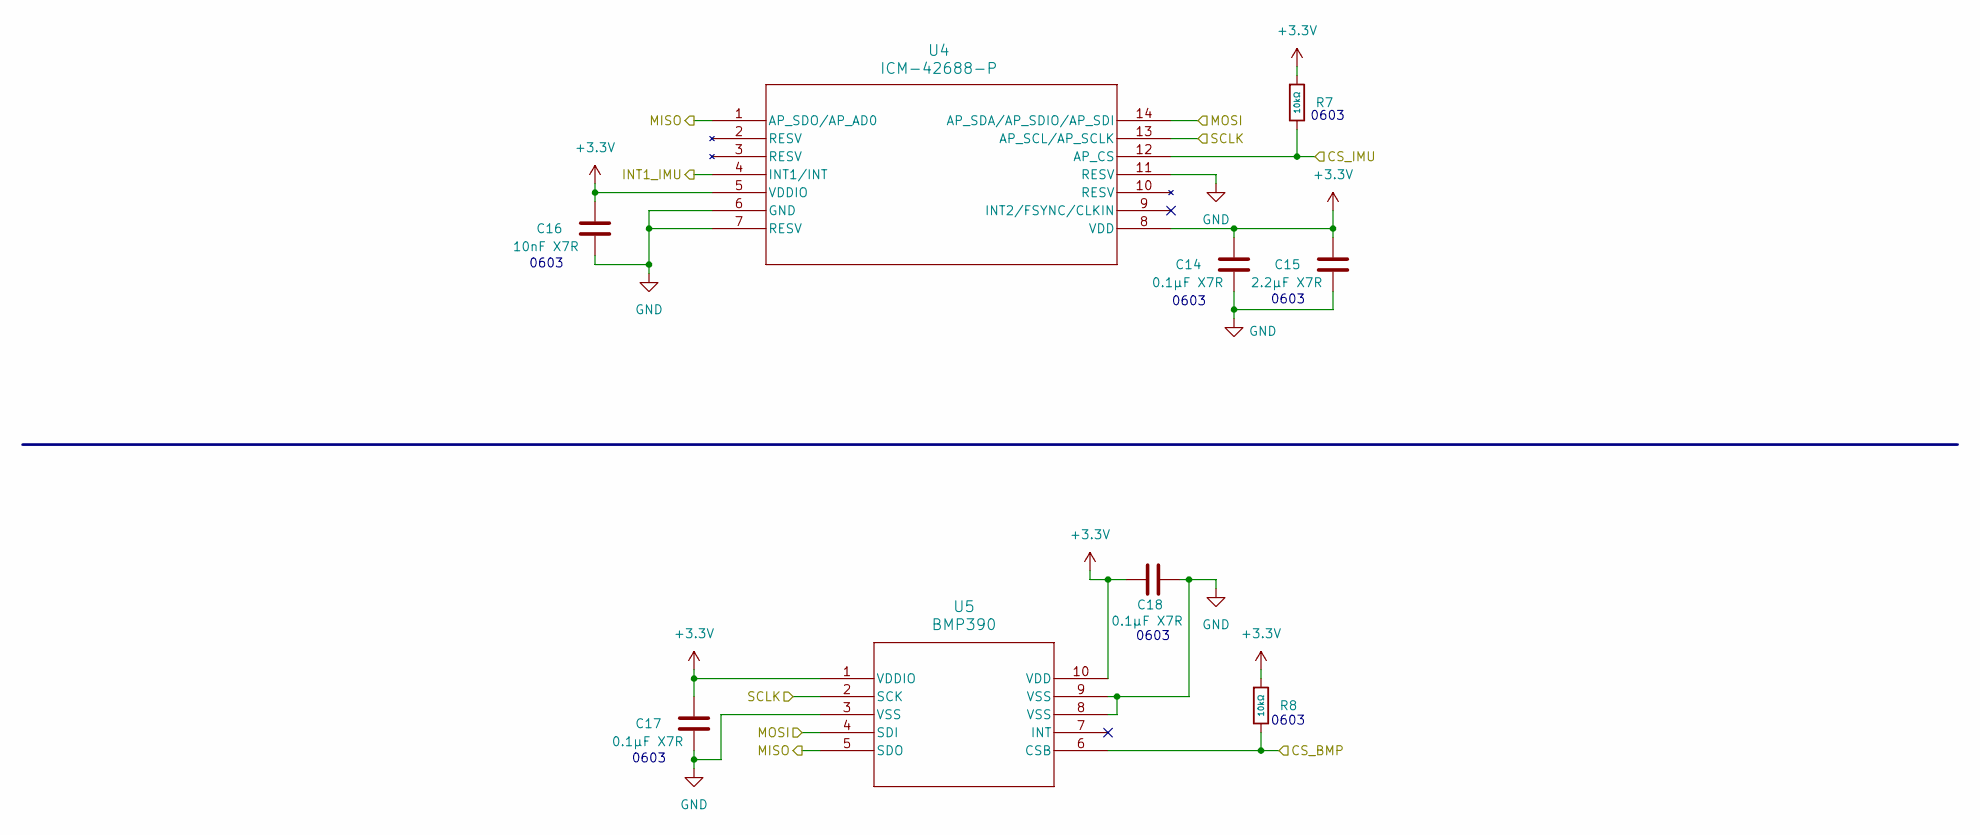
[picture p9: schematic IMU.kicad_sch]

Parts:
C14, C17, C18: 0.1μF X7R; C_0603_1608Metric_Pad1.08x0.95mm_HandSolder; LCSC C1590
C15: 2.2μF X7R; C_0603_1608Metric_Pad1.08x0.95mm_HandSolder; LCSC C43922
C16: 10nF X7R; C_0603_1608Metric_Pad1.08x0.95mm_HandSolder; LCSC C1589
R7, R8: 10kΩ; R_0603; Overload Voltage (Max) 75V; Tolerance ±1%; Part 0603WAF1002T5E; LCSC C25804
U4: ICM-42688-P; ICM-42688-P-M
U5: BMP390

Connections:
+3.3V: C14.1, C15.1, C16.1, C17.1, C18.1, R7.1, R8.1, U4.5 (VDDIO), U4.8 (VDD), U5.1 (VDDIO), U5.10 (VDD); also elsewhere on the board
/IMU/CS_BMP: R8.2, U5.6 (CSB); also elsewhere on the board
/IMU/CS_IMU: R7.2, U4.12 (AP_CS); also elsewhere on the board
/IMU/INT1_IMU: U4.4 (INT1/INT); also elsewhere on the board
/IMU/MISO: U4.1 (AP_SDO/AP_AD0), U5.5 (SDO); also elsewhere on the board
/IMU/MOSI: U4.14 (AP_SDA/AP_SDIO/AP_SDI), U5.4 (SDI); also elsewhere on the board
/IMU/SCLK: U4.13 (AP_SCL/AP_SCLK), U5.2 (SCK); also elsewhere on the board
GND: C14.2, C15.2, C16.2, C17.2, C18.2, U4.6 (GND), U4.7 (RESV), U4.11 (RESV), U5.3 (VSS), U5.8 (VSS), U5.9 (VSS); also elsewhere on the board

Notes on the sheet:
0603

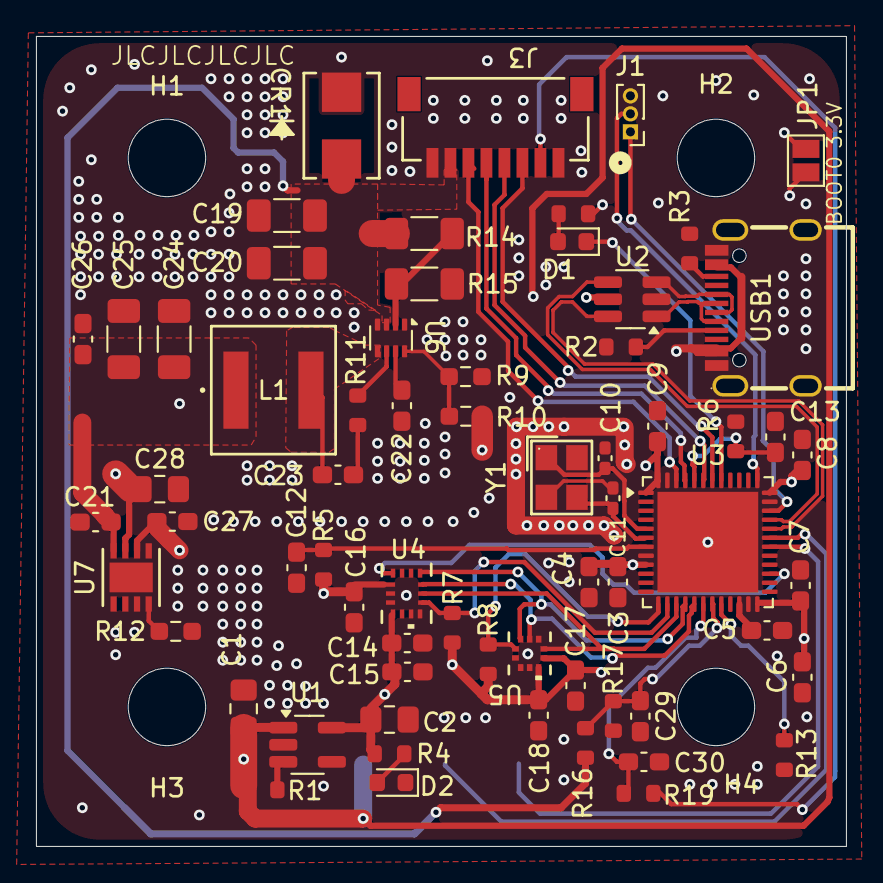
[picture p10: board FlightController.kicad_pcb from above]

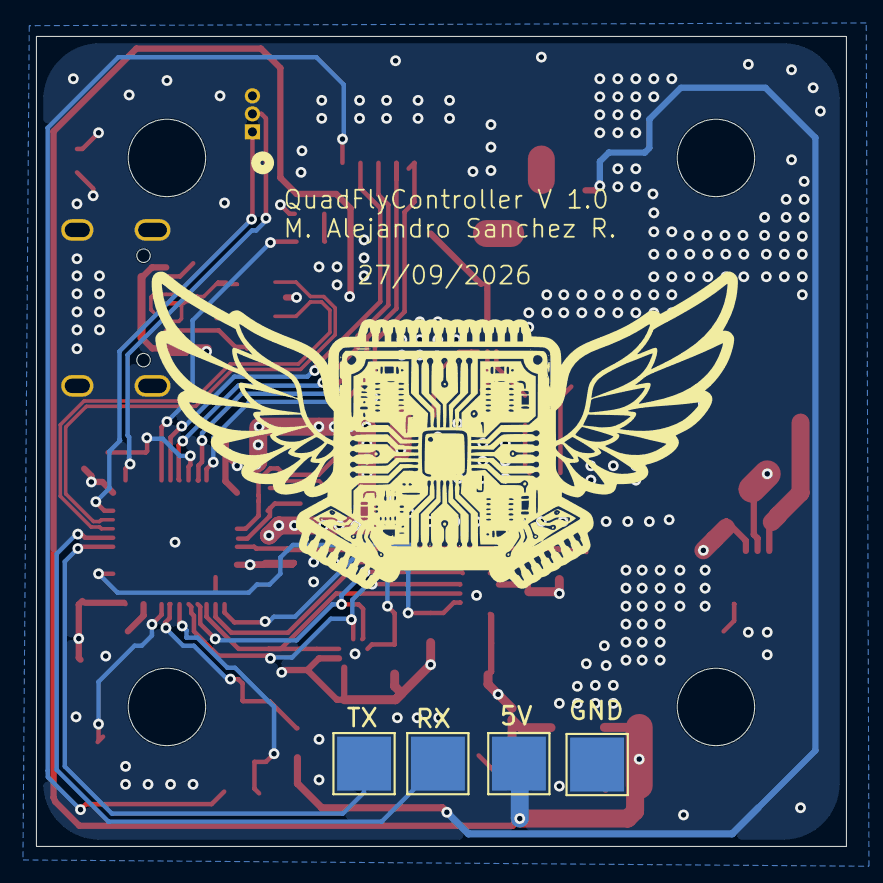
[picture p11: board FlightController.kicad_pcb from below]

Board: 4 copper layers, 45.0 x 45.0 mm, 73 parts (4 on the bottom side), 46 nets.

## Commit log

2026-09-04 Schematic Added (No PCB Layout)
    [FlightController.kicad_pcb, FlightController.kicad_sch, IMU.kicad_sch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]
2026-09-18 Added Part numbers and Buck in PCB
    [FlightController.kicad_pcb, FlightController.kicad_sch, IMU.kicad_sch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]
2026-09-26 Update PCB
    [FlightController.kicad_pcb, MCU.kicad_sch]
2026-09-28 Final Update
    [FlightController.kicad_pcb, FlightController.kicad_sch, FlightController.step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]
